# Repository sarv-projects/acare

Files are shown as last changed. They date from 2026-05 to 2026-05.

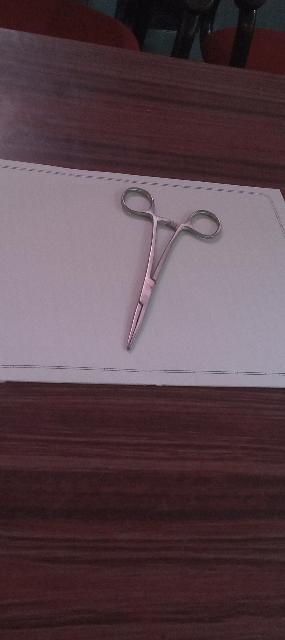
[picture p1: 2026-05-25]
6500e016-cb78-468d-8fea-698199350c50.jpg

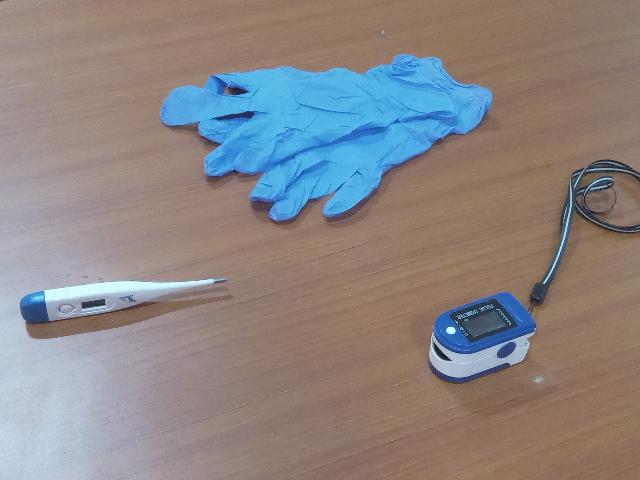
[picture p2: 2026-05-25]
c1362a88-c6d3-454c-b15d-c077ffdc3ec1.jpg

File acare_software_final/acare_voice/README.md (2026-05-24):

# ACARE: Autonomous Clinical Assistance Robot (Voice Module)

ACARE is a robotic assistant designed for clinical environments, specializing in fetching surgical tools via voice commands. This repository contains the **Voice Module**, which handles the complete audio-to-intent pipeline.

---

## 🛠️ Project Structure & File Map

All core logic is located in the `voice/` package:

| File | Purpose | Key Technology |
| :--- | :--- | :--- |
| **`main.py`** | **Entry Point** | Standalone Orchestration |
| `voice/voice_node.py` | **Master Controller** | Audio State Machine & Pipeline Logic |
| `voice/asr.py` | Real-time Transcription | Deepgram Nova-2 (Streaming) |
| `voice/tts.py` | Dual-Engine Speech | **edge-tts** (Neural) & **pyttsx3** (Safety) |
| `voice/vad.py` | Human Speech Detection | Silero VAD (v5) |
| `voice/intent_parser.py`| Command Understanding | Groq (Llama 3 8B) |
| `voice/normaliser.py` | Text Cleaning | Regex-based sanitization |
| `voice/alias_expansion.py`| Tool Mapping | Alias matching (e.g., "blade" → "scalpel") |
| `voice/keyword_monitor.py`| Emergency Monitoring | 100ms Collision Window Listener |
| `voice/assistant_agent.py`| Conversational AI | LOGGED_OUT mode (Assistant guidance) |

---

## ✨ Features Implemented (Done)

- [x] **Dual TTS Architecture**: 
  - **Normal**: Premium Azure Neural via `edge-tts` (completely free, no key needed).
  - **Emergency**: Instant `pyttsx3` offline speech for ESTOP/URGENT alerts.
- [x] **High-Speed ASR**: Real-time streaming from Deepgram with partial transcript handling.
- [x] **Safety First**: Dedicated emergency keyword thread that triggers `<200ms` ESTOP.
- [x] **Intelligent Parsing**: Validates intents with JSON schema enforcement via Groq.
- [x] **Clinical Logic**:
  - Alias expansion for surgical tools.
  - Multi-tool detection (prevents robot from grabbing two things at once).
  - Logged-out assistant mode for auth guidance.

---

## 🚀 How to Run

### 1. Setup Environment
Ensure your `.env` file contains:
* `DEEPGRAM_API_KEY`
* `GROQ_API_KEY`

Sync dependencies using `uv`:
```powershell
uv sync
```

### 2. Execute System
Launch the full standalone voice pipeline:
```powershell
python main.py
```

### 3. Interactive Commands
Once running, type these into the terminal to simulate robot states:
* `login`: Starts the surgical command session.
* `logout`: Returns to assistant guidance.
* `estop`: Forces an emergency stop.
* `resume`: Resets to standby.
* `quit`: Clean shutdown.

---

## 🎙️ Changing the Voice

We use **edge-tts** for natural speech. You can change the robot's personality in `voice/tts.py` on **Line 116**.

| Feature | Voice Name | Description |
| :--- | :--- | :--- |
| **Neutral Robotic** | `en-US-AvaNeural` | **(Current)** Clean, standard AI tone. |
| **Sophisticated** | `en-GB-SoniaNeural` | Crisp British tone, very clear. |
| **Friendly Male** | `en-US-AndrewNeural` | Calm, helpful assistant. |
| **Regional (IN)** | `en-IN-NeerjaNeural` | Natural Indian-English female tone. |

**To change:** Edit `voice/tts.py`:
```python
# Line 116
voice = "en-US-AvaNeural" 
```
You can also use `edge-tts --list-voices`  command in the terminal to list all other available voices.

---

## 🧪 Testing Sub-Modules
You can test components individually:
* **TTS Test**: `python -m voice.tts`
* **Normaliser Test**: `python -m voice.normaliser`
* **Alias Test**: `python -m voice.alias_expansion`

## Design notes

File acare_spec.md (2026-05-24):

# ACARE
## Autonomous Clinical Assistance Robot with Multimodal Biometric Authentication and Dynamic Human Handover

---

| Field | Details |
|---|---|
| Institution | Ramaiah Institute of Technology, Bengaluru |
| Department | Electronics and Communication Engineering |
| Guide | Dr. Lakshmi Shrinivasan, Associate Professor |
| Team | Sathvik Rao · Sarvesh Bhattacharyya · Shreevanth M · Shreyas S |
| Funding | ₹40,000 — Institutional Grant |
| Status | Active Development — April 2026 |

---

## DOMAIN MAP

| Domain | Scope |
|---|---|
| SOFTWARE | AI pipelines, ROS2 nodes, orchestration, admin CLI |
| HARDWARE | Mechanical, electrical, power, physical components |
| EMBEDDED / FIRMWARE | Teensy 4.1 motor control, sensor ISR loops, PID |
| INTEGRATION BOUNDARY (SOFTWARE + ELECTRONICS/EMBEDDED) | Protocol contracts between software and embedded |

---

## TABLE OF CONTENTS

- Section I — Project Overview
- Section II — Hardware Architecture
- Section III — Embedded Firmware — Teensy 4.1 / Cortex-M4 + ESP32
- Section IV — Software ↔ Embedded Integration Boundary
- Section V — ROS2 Software Architecture
- Section VI — Global Robot State Machine
- Section VII — Identity & Session Management
- Section VIII — Voice Orchestration Layer
- Section IX — Voice Command Pipeline
- Section X — Conversational Layer — LangGraph + Assistant Agent
- Section XI — Vision Pipeline — NBV Search & Detection
- Section XII — Task Planner Pipeline
- Section XIII — Emergency Stop System
- Section XIV — LiDAR Safety System
- Section XV — Response Generator — TTS
- Section XVI — Logging & Audit Trail
- Section XVII — Startup, Shutdown & Power Recovery
- Section XVIII — Admin CLI & Calibration
- Section XIX — Configuration Files
- Section XX — Directory Structure
- Section XXI — Complete Technology Stack
- Section XXII — Performance KPIs
- Section XXIII — Preliminary Work Status — March 2026
- Section XXIV — Supplementary Implementation Details
- Section XXV — Commercial Applications & Future Work
- Section XXVI — Complete System Flow & Final Decisions (Full Operational Reference)

---

## SECTION I — PROJECT OVERVIEW

### Objective

ACARE is a stationary 6-DOF semi-autonomous robotic arm designed for clinical environments — specifically plastic surgery departments — where surgical tools must be fetched and delivered to authorised staff repeatedly across long procedure shifts. The robot replaces the manual, hygiene-risk-bearing task of instrument handling by providing a voice-commanded, biometrically authenticated, autonomous pick-and-place system with human oversight.

### Core Problems Solved

- Staff fatigue from repetitive tool retrieval during 10–12-hour surgical shifts
- Hygiene risks from manual handling of sterile instruments
- Procedure delays caused by instrument unavailability or incorrect delivery
- Absence of affordable autonomous assistance solutions in Indian healthcare settings

### Scope — Finalised

- Stationary pick-and-place operation only — navigation removed from scope
- Contactless operation — entirely voice commanded, no physical input required
- Dual biometric authentication — voice and face combined for every session
- Single active user session at any time — one command per turn
- Single tool per command — multi-tool requests handled via clarification dialogue
- Next-Best-View intelligent search — not continuous scanning
- Direct handover — tool delivered from gripper directly into authenticated staff's hand

### System Architecture Summary

ACARE is a two-layer hierarchical robotic system. The high-level intelligence layer runs on a Raspberry Pi 5 using ROS2. The real-time motor control layer runs on a Teensy 4.1 (Cortex-M7).

These two layers communicate via CAN bus (preferred) or UART. All AI and software pipelines are isolated from hardware control.

- SOFTWARE — Raspberry Pi 5 + ROS2 + Python AI Nodes
- EMBEDDED / FIRMWARE — Teensy 4.1 / Cortex-M4 + ESP32 + PID + Safety ISR
- HARDWARE — 6-DOF Arm + Sensors + Power System

### Key Differentiation vs Prior Art

Unlike MOXI, TIAGo, TUG, or LIO, ACARE integrates multimodal biometric authentication (voice + face), voice-driven instrument retrieval with structured intent parsing, adaptive probabilistic vision search, and dynamic human-robot handover with real-time palm tracking — all within a layered safety architecture that separates high-level intelligence from deterministic motor control.

### Section I-B — System Assumptions & Prerequisites

**Network**

- ACARE requires stable internet connectivity during operation
- Two cloud services are mandatory: Deepgram Nova-2 (STT streaming WebSocket) and Groq API (intent parsing)
- Microsoft Edge TTS API required for natural voice responses
- If connectivity drops mid-session: voice commands stop processing; system transitions to STANDBY or ESTOP (safe deposit if holding)
- There is no offline fallback mode by design. The system either works fully or stops cleanly. Degraded mode does not exist.
- A stable Wi-Fi connection at the deployment site is a prerequisite. Mobile hotspot recommended as backup for demo.

**Power**

- Continuous 24V motor supply required
- 5V regulated logic supply required
- Power failure triggers recovery sequence on reboot

**Physical**

- Fixed workspace — robot does not navigate
- SAFE_DROP_ZONE and handover zone positions fixed at calibration
- Staff must approach from designated handover direction

### Future Work Preview

Long-term extensions include integration with hospital automation systems, smart operating room orchestration, and expansion to multi-robot clinical assistance fleets. See Section XXV for detailed commercial roadmap.

---

## SECTION II — HARDWARE ARCHITECTURE

> **HARDWARE** — All mechanical design, fabrication, PCB design, power electronics, and physical sensor mounting falls under the Hardware domain.

### Mechanical Structure

- 6-DOF serial robotic arm
- Custom 3D printed cycloidal gearboxes — 22:1 ratio at shoulder, 15:1 at elbow
- Gearbox ratios for wrist joints 4, 5, 6: [PLACEHOLDER — confirm with hardware team]
- Material: PETG high infill for gearbox bodies; aluminium sheet metal for structural load-bearing links
- Radial bearings at all rotating joints
- Precision gripper mechanism with integrated force sensor
- Bowden line pulley system for wrist actuation
- Fixed handover zone — staff approaches and receives tool directly from gripper; position encoded in config
- Fixed SAFE_DROP_ZONE — predefined emergency deposit surface on table; (x, y, z) stored in config
- Base fixation method: [PLACEHOLDER — bolted to table / clamped / weighted base — confirm]

### Joint Parameters — Required from Hardware Team

> **CRITICAL:** IK solver and planner_node cannot be built without these values.

| Joint | Name | Min Angle (rad) | Max Angle (rad) | Max Velocity (rad/s) | Home Position (rad) | Gear Ratio |
|---|---|---|---|---|---|---|
| Joint 1 | Base Rotation | [PLACEHOLDER] | [PLACEHOLDER] | [PLACEHOLDER] | 0.0 | [PLACEHOLDER] |
| Joint 2 | Shoulder | [PLACEHOLDER] | [PLACEHOLDER] | [PLACEHOLDER] | [PLACEHOLDER] | 20:1 |
| Joint 3 | Elbow | [PLACEHOLDER] | [PLACEHOLDER] | [PLACEHOLDER] | [PLACEHOLDER] | 15:1 |
| Joint 4 | Wrist Pitch | [PLACEHOLDER] | [PLACEHOLDER] | [PLACEHOLDER] | 0.0 | [PLACEHOLDER] |
| Joint 5 | Wrist Roll | [PLACEHOLDER] | [PLACEHOLDER] | [PLACEHOLDER] | 0.0 | [PLACEHOLDER] |
| Joint 6 | Gripper Rotate | [PLACEHOLDER] | [PLACEHOLDER] | [PLACEHOLDER] | 0.0 | [PLACEHOLDER] |

### Link Lengths — Required from Hardware Team

| Link | Description | Length (metres) |
|---|---|---|
| Base height | Base to shoulder joint (vertical) | [PLACEHOLDER] |
| Upper arm | Shoulder to elbow | [PLACEHOLDER] |
| Forearm | Elbow to wrist | [PLACEHOLDER] |
| Wrist | Wrist joint to gripper mount | [PLACEHOLDER] |
| Gripper | Gripper mount to fingertips | [PLACEHOLDER] |
| Total reach | Maximum horizontal reach | [PLACEHOLDER] |

### DH Parameters — Required from Hardware Team

Denavit-Hartenberg parameters needed for IK solver. Fill in after assembly.

| Joint | a (m) | alpha (rad) | d (m) | theta offset (rad) |
|---|---|---|---|---|
| 1 | [PLACEHOLDER] | [PLACEHOLDER] | [PLACEHOLDER] | [PLACEHOLDER] |
| 2 | [PLACEHOLDER] | [PLACEHOLDER] | [PLACEHOLDER] | [PLACEHOLDER] |
| 3 | [PLACEHOLDER] | [PLACEHOLDER] | [PLACEHOLDER] | [PLACEHOLDER] |
| 4 | [PLACEHOLDER] | [PLACEHOLDER] | [PLACEHOLDER] | [PLACEHOLDER] |
| 5 | [PLACEHOLDER] | [PLACEHOLDER] | [PLACEHOLDER] | [PLACEHOLDER] |
| 6 | [PLACEHOLDER] | [PLACEHOLDER] | [PLACEHOLDER] | [PLACEHOLDER] |

### Workspace Validation

Defined workspace: xmin: -0.4m to xmax: 0.4m, ymin: -0.3m to ymax: 0.3m, zmin: 0.0m to zmax: 0.5m.

Workspace reachability confirmation: [PLACEHOLDER — verify arm can physically reach all corners of defined workspace after assembly]

### Gripper Specifications

| Parameter | Value |
|---|---|
| Type | Parallel jaw |
| Finger material | [PLACEHOLDER] |
| Maximum jaw opening | [PLACEHOLDER] mm |
| Default grasp width | 25 mm (most tools) |
| Open width | 45 mm |
| Closed width | 0 mm |
| Force control mode | Yes — not simple open/close |
| Force target (normal grasp) | 3–5 N |
| Force warning threshold | 10 N |
| Force ESTOP threshold | 15 N |
| Tool retention during transport | [PLACEHOLDER — friction / mechanical lock / force hold] |
| Open time | ~500 ms |
| Close time | ~500 ms |

### Weight and Load

- Estimated arm weight: [PLACEHOLDER — total arm weight in kg]
- Maximum payload at end-effector: [PLACEHOLDER — kg, confirm motors can handle]
- Per-link weight distribution: [PLACEHOLDER]

### Actuators

- BLDC motors: 1.4 Nm Rhino Planetary Gearbox BLDC — base, shoulder, elbow joints (×3)
- Additional BLDC motors for wrist and gripper actuation
- Gripper motor controlled in force mode — not position mode
- Motor driver: [RMCS-3002l]
- Motor driver communication to Teensy: [Modbus ASCII]
- Current sensing method: [PLACEHOLDER — shunt resistor / hall sensor]

### Sensors — Full List

| Sensor | Model / Type | Location | Domain |
|---|---|---|---|
| RGBD Depth Camera | YDLIDAR HP60C | Wrist-mounted | Hardware / Software |
| Safety LiDAR | YDLIDAR T-mini-Plus | Base-mounted ~80cm | Hardware / Software |
| Joint Encoders | AS5600 Magnetic Encoder ×6 | Each joint | Hardware / Embedded |
| IMU | On MCU board | Arm base | Hardware / Embedded |
| Joint Current Sensors | Per motor phase | Motor driver board | Hardware / Embedded |
| Temperature Sensors | Per joint motor | Joint housings | Hardware / Embedded |
| Gripper Force Sensor | Analog force sensing | Gripper fingertips | Hardware / Embedded |
| Microphone | [PLACEHOLDER — model, polar pattern, USB/3.5mm] | Fixed mount near workspace | Hardware / Software |
| Speaker | [PLACEHOLDER — model, amplifier if any] | [PLACEHOLDER — mounting location] | Hardware / Software |
| I2C Multiplexer | TCA9548A | MCU board | Hardware / Embedded |

### Camera Interface

- YDLIDAR HP60C connection to Pi: [PLACEHOLDER — USB3 / proprietary — confirm interface]
- ROS2 driver package for HP60C: [PLACEHOLDER — confirm package name]
- YDLIDAR T-mini Plus connection to Pi: [PLACEHOLDER — USB / Serial — confirm]
- ROS2 driver package for T-mini Plus: [PLACEHOLDER — confirm package name]

### Microphone Specification

- Model: [PLACEHOLDER]
- Polar pattern: [PLACEHOLDER — cardioid / supercardioid recommended for OT noise rejection]
- Connection type: [PLACEHOLDER — USB / 3.5mm / XLR]
- Distance from speaker: [PLACEHOLDER — ensure sufficient separation to prevent feedback]

### Speaker Specification

- Model: [PLACEHOLDER]
- Amplifier: [PLACEHOLDER — if required]
- Mounting location: [PLACEHOLDER — near workspace, facing staff area]
- Volume requirement: sufficient to be heard in active OT environment over monitor beeps

### Cable Management

- Wrist camera cable routing: [PLACEHOLDER — flex-rated cable required through rotating joints]
- Encoder cable routing: [PLACEHOLDER — per joint, shielded recommended]
- Motor power cable gauge: [PLACEHOLDER — sized for 8A continuous per motor]
- Emergency stop button cable: direct hardwire to motor driver enable pin, no software path

### Power System

- Motor supply: 24V dedicated rail — powers all BLDC motors and motor drivers
- Logic supply: 5V regulated — powers Raspberry Pi 5, isolated from motor rail
- MCU supply: 5V or 3.3V from onboard regulator
- Common ground across all supplies — mandatory for signal integrity
- Fuse on motor supply rail — overcurrent protection
- Reverse polarity protection on all input rails
- Surge protection — motor switching transients isolated from logic supply
- EMI filtering between motor supply and Pi supply — implementation: [PLACEHOLDER — ferrite beads / LC filter / isolated transformer]
- Hardware emergency cutoff relay — physical red button wired directly to motor driver enable pin, cuts 24V immediately, independent of all software
- XT30 male connectors for battery/PSU to motor controller connections

### Connector Specifications

| Connection | Connector Type | Notes |
|---|---|---|
| Motor rail to driver | XT30 male/female | 24V, high current rated |
| Encoder to TCA9548A | [PLACEHOLDER] | I2C, shielded cable |
| Camera (HP60C) to Pi | [PLACEHOLDER] | USB3 / proprietary |
| LiDAR to Pi | [PLACEHOLDER] | USB / Serial |
| ESTOP button | Direct hardwire | To motor driver enable pin |
| Pi to MCU (CAN) | [PLACEHOLDER] | Galvanic isolation between Pi and MCU |
| CAN bus termination | [PLACEHOLDER] | 120 ohm termination resistors at both ends |

### Thermal Management

- Raspberry Pi 5 cooling: active fan required — confirmed risk of thermal throttling under full load
- Pi 5 thermal test: must run under full load (YOLOv11 + SpeechBrain + ROS2 + TTS) for 30 minutes before demo — confirm no throttling
- Motor housing ventilation: [PLACEHOLDER — confirm passive or active cooling per motor]
- Enclosure thermal design: [PLACEHOLDER — if enclosed, ensure airflow]

### Physical Layout Constraints

- SAFE_DROP_ZONE: flat horizontal surface within arm reach, defined during calibration, stored in config as (x, y, z)
- Handover zone: fixed position, staff approaches from designated direction and receives directly from gripper
- LiDAR mounted at approximately 80cm height — scans horizontal plane at torso level
- Camera wrist-mount angle: calibrated during setup, extrinsics stored in config
- Arm base mounting: [PLACEHOLDER — how base is fixed to table/surface]

---

## SECTION III — EMBEDDED FIRMWARE — Teensy 4.1 / Cortex-M4 + ESP32

> **EMBEDDED / FIRMWARE** — All firmware, PID implementation, ISR routines, watchdog logic, and calibration sequences fall under the Embedded domain.

### MCU Selection

Teensy 4.1 selected for current implementation — Cortex-M7 at 600MHz. Final target is a custom PCB integrating Cortex-M4 for motor control and ESP32 for Pi communication only. ESP32 not used for motor control — WiFi jitter is incompatible with deterministic PID.

### PCB Design Specification

- Custom PCB status: [PLACEHOLDER — in progress]
- MCU: Cortex-M4 for motor control
- WiFi/BT: ESP32 for Pi communication only
- Layer count: [PLACEHOLDER]
- Connector types: [PLACEHOLDER]
- Galvanic isolation: [PLACEHOLDER — how implemented between Pi and MCU]
- Schematic reference: [PLACEHOLDER — attach or link schematic]

### Control Loop Architecture

| Loop | Frequency | Responsibility |
|---|---|---|
| Velocity PID | 200 Hz | Motor velocity regulation from position derivative |
| Position PID | 200 Hz | Joint angle tracking from encoder feedback |
| Sensor Read | 100 Hz | Encoder, current, temperature, gripper force, IMU |
| Status Publish to Pi | 50 Hz | JSON status packet over CAN/UART |
| Heartbeat Check | 5 Hz | Verify Pi heartbeat received within 500ms window |

### Per-Joint Control Stack

```
Position PID → Velocity PID → Frequency → Motor driver → BLDC motor
     ↑ Encoder feedback + Current feedback
```

### PID Parameters — Initial Values

> Note: these are starting values for tuning. Final values determined empirically after assembly.

| Joint | Position Kp | Position Ki | Position Kd | Velocity Kp | Velocity Ki | Velocity Kd |
|---|---|---|---|---|---|---|
| Joint 1 (Base) | [PLACEHOLDER] | [PLACEHOLDER] | [PLACEHOLDER] | [PLACEHOLDER] | [PLACEHOLDER] | [PLACEHOLDER] |
| Joint 2 (Shoulder) | [PLACEHOLDER] | [PLACEHOLDER] | [PLACEHOLDER] | [PLACEHOLDER] | [PLACEHOLDER] | [PLACEHOLDER] |
| Joint 3 (Elbow) | [PLACEHOLDER] | [PLACEHOLDER] | [PLACEHOLDER] | [PLACEHOLDER] | [PLACEHOLDER] | [PLACEHOLDER] |
| Joint 4 (Wrist Pitch) | [PLACEHOLDER] | [PLACEHOLDER] | [PLACEHOLDER] | [PLACEHOLDER] | [PLACEHOLDER] | [PLACEHOLDER] |
| Joint 5 (Wrist Roll) | [PLACEHOLDER] | [PLACEHOLDER] | [PLACEHOLDER] | [PLACEHOLDER] | [PLACEHOLDER] | [PLACEHOLDER] |
| Joint 6 (Gripper) | [PLACEHOLDER] | [PLACEHOLDER] | [PLACEHOLDER] | [PLACEHOLDER] | [PLACEHOLDER] | [PLACEHOLDER] |

- Anti-windup strategy: [PLACEHOLDER — clamping / back-calculation]
- Feed-forward terms: [PLACEHOLDER — gravity compensation per joint]
- PWM carrier frequency: [PLACEHOLDER — kHz]
- PWM resolution: [PLACEHOLDER — bits]
- FOC switching frequency: [PLACEHOLDER — kHz]
- Dead time for complementary outputs: [PLACEHOLDER — ns]

### Encoder Reading Implementation

- I2C clock speed for AS5600: [PLACEHOLDER — Hz, typically 400kHz]
- Address assignment per TCA9548A channel: [PLACEHOLDER — channel 0 = joint 1, etc.]
- Read method: [PLACEHOLDER — interrupt-driven / polling at 100Hz]
- Encoder count to angle conversion: `angle_rad = (raw_count / 4096) × 2π`
- Zero position calibration storage: [PLACEHOLDER — EEPROM / Flash — location and format]
- Exponential moving average filter on encoder: `filtered = 0.7 × raw + 0.3 × prev`

### Embedded Internal State Machine

| State | Description | Allowed Transitions |
|---|---|---|
| IDLE | Powered, no commands, holding position | → POSITION_CONTROL, → CALIBRATION |
| POSITION_CONTROL | Executing joint position targets from Pi | → GRIPPER_CONTROL, → ESTOP, → FAULT, → IDLE |
| GRIPPER_CONTROL | Force-mode gripper operation | → POSITION_CONTROL, → ESTOP, → FAULT |
| ESTOP | PWM disabled, motors free or braked | → IDLE (only after CLEAR_FAULT from Pi) |
| FAULT | Unrecoverable hardware fault detected | → ESTOP, requires admin reset |
| CALIBRATION | Joint homing sequence | → IDLE on completion |

### Firmware Safety Protections — Non-Negotiable

- Current clamp: if joint_current > 8A for >100ms → ESTOP
- Thermal shutdown: if joint_temp > 65°C → reduce velocity 50%. If temp > 75°C → ESTOP
- Encoder soft limits: if encoder value exceeds mechanical boundary → ESTOP
- Watchdog timer: firmware hang → MCU hardware reset
- Pi heartbeat watchdog: no heartbeat for 500ms → disable all PWM → ESTOP
- Hardware ESTOP pin: physical red button → cuts PWM immediately at hardware level
- Boot calibration timeout: if joint does not reach limit switch within [PLACEHOLDER] seconds → FAULT

### Fault Code Definitions

| fault_code | Meaning | Recovery |
|---|---|---|
| 0 | OK — no fault | — |
| 1 | Overcurrent — joint current > 8A | CLEAR_FAULT after inspection |
| 2 | Overtemperature — joint temp > 75°C | CLEAR_FAULT after cooling |
| 3 | Encoder soft limit exceeded | CLEAR_FAULT after repositioning |
| 4 | Velocity limit exceeded > 120 deg/s | CLEAR_FAULT |
| 5 | Gripper force spike > 15N | CLEAR_FAULT after inspection |
| 6 | Heartbeat timeout — Pi silent > 500ms | Auto-recovers when heartbeat resumes |
| 7 | Firmware watchdog reset | CLEAR_FAULT after admin review |
| 8 | Boot calibration timeout | Admin must manually home joint |

### Pre-Threshold Warning Margins

- Joint current: Warning at 6A (−25% velocity). Hard ESTOP at 8A.
- Joint temperature: Warning at 55°C (−25% velocity). Slowdown at 65°C (−50%). ESTOP at 75°C.
- Gripper force: Target 3–5N. Warning at >10N. ESTOP at >15N.
- Joint velocity: Operational limit 80 deg/s. Hard ESTOP at 120 deg/s.

### Gripper Force Control Logic

- Force control mode — not simple open/close
- Apply increasing current until target force threshold reached, then maintain minimum holding torque
- Force spike > 15N → immediate ESTOP (unexpected contact)
- Object drop detection: force drops to zero during HOLDING → notify planner_node via /motion_feedback
- Gripper fully opens before arm approaches grasp position — GRIPPER_OPEN awaited first

### Boot Calibration Sequence

- Move each joint slowly toward mechanical limit switch, detect contact, zero encoder offset
- Repeat for all 6 joints in defined sequence (joint 1 → 6)
- Set all joint soft-limits from calibrated zeros
- Report CALIBRATION_COMPLETE to Pi
- Timeout per joint: [PLACEHOLDER] seconds — if not reached → fault_code 8

---

## SECTION IV — SOFTWARE ↔ EMBEDDED INTEGRATION BOUNDARY

> **INTEGRATION BOUNDARY** — Protocol contract between embedded_interface_node (software) and Teensy 4.1 firmware. Both teams must implement their side identically.

### Physical Communication Layer

- Primary: UART — recommended for noise immunity and multi-drop support
- Fallback: UART at minimum 1 Mbps
- UART frame format: [PLACEHOLDER — standard 11-bit / extended 29-bit]
- Byte packing: little-endian, float32 IEEE 754
- Do not use I2C or SPI for Pi ↔ MCU communication
- Galvanic isolation: [PLACEHOLDER — implementation between Pi and MCU]
- UART format — framing: [PLACEHOLDER — start byte, length, payload, CRC]

### Startup Handshake

- On boot, MCU waits for first HEARTBEAT from Pi before entering IDLE
- Pi embedded_interface_node waits for CALIBRATION_COMPLETE from MCU before accepting any commands
- If Pi boots before MCU calibration completes: Pi polls, retries every 500ms, max 60 seconds
- If MCU does not send CALIBRATION_COMPLETE within 60 seconds: Pi publishes ESTOP, TTS: 'Calibration failed. Admin required.'

### Pi Heartbeat — Implementation

```cpp
// embedded_interface_node (C++) sends every 200ms:
{ "command":"HEARTBEAT", "timestamp": unix_ms, "robot_state": current_state_string }

// MCU side:
if(millis() - last_heartbeat_ms > 500){ disable_all_pwm(); enter_estop(); }
```

### Pi → MCU Commands

| Command | Fields | Description |
|---|---|---|
| MOVE | joint_angles[6] (float32), velocity_scale (float32), accel_limit (float32) | Move all joints to target positions |
| GRASP | force_target (float32, Newtons) | Close gripper in force control mode |
| RELEASE | — | Open gripper fully |
| MOVE_NEUTRAL | — | Return to predefined neutral position |
| ESTOP | — | Immediate PWM disable |
| CLEAR_FAULT | — | Reset after fault resolution |
| CALIBRATE | — | Trigger boot calibration sequence |
| HEARTBEAT | timestamp (int64), robot_state (string) | 200ms keepalive |

### MCU → Pi Status (50 Hz)

| Field | Type | Description |
|---|---|---|
| joint_positions | float32[6] | Current joint angles in radians |
| joint_velocities | float32[6] | Current joint velocities in rad/s |
| joint_currents | float32[6] | Per-joint motor current in Amperes |
| temperatures | float32[6] | Per-joint temperature in °C |
| gripper_force | float32 | Current gripper contact force in N |
| imu | roll, pitch, yaw (float32) | Arm orientation from IMU |
| fault_code | int32 | 0 = OK, see fault code table for non-zero values |
| control_state | string | IDLE / POSITION_CONTROL / GRIPPER_CONTROL / ESTOP / FAULT |

### Workspace Boundary Contract

Software enforces workspace limits before sending any MOVE command. Embedded enforces joint soft-limits independently. Both layers protect — neither relies solely on the other.

```
workspace: xmin:-0.4  xmax: 0.4  ymin:-0.3  ymax: 0.3  zmin: 0.0  zmax: 0.5  (metres)
```

---

## SECTION V — ROS2 SOFTWARE ARCHITECTURE

> **SOFTWARE** — All ROS2 nodes, topics, message definitions, launch files, and Python AI logic fall under the Software domain.

### Execution Model

- MultiThreadedExecutor runs all nodes concurrently. No monolithic Python process.
- One node per concern. Nodes communicate exclusively via typed ROS2 topics.
- Vision inference (YOLOv11) and speaker verification (SpeechBrain) must not run simultaneously.
- embedded_interface_node runs in a dedicated MutuallyExclusive callback group — heartbeat cannot share thread pool with vision or TTS.

### Node Inventory

| Node | Package | Language | Responsibility |
|---|---|---|---|
| voice_node | acare_voice | Python | Audio I/O, VAD, STT, TTS, emergency keyword thread, assistant agent (LOGGED_OUT) |
| dialogue_node | acare_dialogue | Python | LangGraph, intent clarity, context resolution, interruption, assistant agent routing |
| auth_node | acare_auth | Python | Dual biometric verification, session management, enrolment, scripted auth flow, handover face check |
| vision_node | acare_vision | Python | YOLOv11 ONNX, NBV search, Bayesian probability map, fake detection, 3D localisation, hand tracking |
| planner_node | acare_planner | Python | Full task orchestration, IK, handover protocol (3-check), state transitions, latency tracking, world state snapshot |
| embedded_interface_node | acare_embedded_interface | C++ | CAN/UART bridge, heartbeat, command serialisation — MutuallyExclusive callback group |
| safety_node | acare_safety | Python | LiDAR proximity, sensor threshold monitoring, graded severity (WARNING/CRITICAL/ESTOP) |
| state_manager | acare_planner | Python | Global robot state machine, atomic transition enforcement, graded severity handling |
| log_node | acare_logging | Python | SQLite audit trail, full pipeline latency fields, log rotation |
| admin_node | acare_admin | Python | CLI interface, enrolment, calibration, demo mode, diagnostics |

### Node Crash Recovery

- Lightweight `supervisor.py` (separate from ROS2) monitors node health and auto-restarts non-critical nodes
- Auto-restart (non-critical): log_node, admin_node, dialogue_node
- No auto-restart (critical): safety_node, embedded_interface_node, state_manager, planner_node
- On critical node crash: publish ESTOP, TTS: 'System fault detected. Admin required.', State → ERROR

### ROS2 QoS Policy

| Topic Category | QoS | Rationale |
|---|---|---|
| Sensor data (/motion_feedback, /lidar_scan) | BEST_EFFORT | Drop stale data; always use latest |
| Commands (/arm_command, /gripper_command, /emergency_stop) | RELIABLE | Guaranteed delivery — never drop |
| State topics (/robot_state, /state_transition, /safety_alert) | RELIABLE | All nodes must see state changes |
| Logging (/log_event) | BEST_EFFORT | Log loss acceptable; never block pipeline |

### Topic Structure

| Topic | Message Type | Publisher → Subscriber |
|---|---|---|
| /robot_state | RobotState | state_manager → all nodes |
| /state_transition | StateTransition | any node → state_manager |
| /raw_transcript | Transcript | voice_node → dialogue_node |
| /intent_result | Intent | dialogue_node → auth_node |
| /validated_intent | ValidatedIntent | auth_node → planner_node |
| /emergency_stop | EmergencySignal | voice_node / safety_node → all nodes + embedded_interface |
| /auth_request | AuthRequest | dialogue_node → auth_node |
| /auth_result | AuthResult | auth_node → planner_node |
| /vision_search_request | VisionSearchRequest | planner_node → vision_node |
| /vision_result | VisionResult | vision_node → planner_node |
| /probability_update | ProbabilityUpdate | vision_node → vision_node (internal) |
| /arm_command | ArmCommand | planner_node → embedded_interface_node |
| /gripper_command | GripperCommand | planner_node → embedded_interface_node |
| /motion_feedback | MotionFeedback | embedded_interface_node → planner_node |
| /lidar_scan | LaserScan | safety_node (internal), velocity scale → planner |
| /safety_alert | SafetyAlert | safety_node → planner_node + state_manager |
| /log_event | LogEvent | all nodes → log_node |
| /vision_status | VisionStatus | vision_node → planner_node (LOADING / READY) |
| /hand_status | HandStatus | vision_node → planner_node (handover hand detection) |
| /tts_request | String | dialogue_node, planner_node → voice_node |

### Custom Message Definitions — acare_msgs Package

```
RobotState.msg
string state  # OFFLINE|LOGGED_OUT|STANDBY|LISTENING|PROCESSING|EXECUTING|HOLDING|HANDOVER|ESTOP|ERROR
string active_user_id

Intent.msg
string tool
string action
string destination  # always 'user_handover' — hardcoded in planner
float32 confidence

ValidatedIntent.msg
string tool
string action
string user_id
bool authenticated

SafetyAlert.msg
string reason
string source  # voice|lidar|current|temp|velocity|gripper|network
string severity  # WARNING|CRITICAL|ESTOP

HandStatus.msg
bool hand_detected
bool is_open
bool palm_up
float32 x
float32 y
float32 z
float32 confidence

AuthResult.msg
string user_id
string name
string role
bool success
bool face_verified
float32 face_confidence

VisionResult.msg
bool found
string tool
float32 x
float32 y
float32 z
float32 confidence
string zone
string[] candidates  # alternative detection candidates for IK fallback

ArmCommand.msg
string command  # MOVE|GRASP|RELEASE|MOVE_NEUTRAL|ESTOP|CLEAR_FAULT|CALIBRATE|HEARTBEAT
float32[] joint_angles
float32 velocity_scale  # 0.0–1.0, set by safety_node proximity zone
bool blocking

MotionFeedback.msg
bool success
string phase  # PRE_GRASP|GRASP|HOLDING|HANDOVER|NEUTRAL|VIEWPOINT
string error  # empty if success

LogEvent.msg
string event_type
string user_id
string tool
string state
string description
int64 timestamp
int64 voice_e2e_ms    # VAD trigger → validated_intent published
int64 vision_search_ms  # search start → VisionResult received
int64 motion_ms       # MOVE command → MotionFeedback.success
int64 total_task_ms   # ValidatedIntent → handover complete
string safety_severity  # WARNING|CRITICAL|ESTOP for safety events

EmergencySignal.msg
string reason
string source
```

### Launch File

```python
# ros2 launch acare_bringup acare.launch.py
def generate_launch_description():
    return LaunchDescription([
        Node(package="acare_voice",              executable="voice_node"),
        Node(package="acare_dialogue",           executable="dialogue_node"),
        Node(package="acare_auth",               executable="auth_node"),
        Node(package="acare_vision",             executable="vision_node"),
        Node(package="acare_planner",            executable="planner_node"),
        Node(package="acare_planner",            executable="state_manager"),
        Node(package="acare_safety",             executable="safety_node"),
        Node(package="acare_embedded_interface", executable="interface_node"),
        Node(package="acare_logging",            executable="log_node"),
        Node(package="acare_admin",              executable="admin_node"),
    ])
```

---

## SECTION VI — GLOBAL ROBOT STATE MACHINE

> **SOFTWARE** — Enforced by state_manager node. Embedded firmware has its own independent state machine.

| State | Description | Allowed Transitions |
|---|---|---|
| OFFLINE | System idle, no processes running | → LOGGED_OUT on boot |
| LOGGED_OUT | System running, no active session | → STANDBY on login |
| STANDBY | Session active, awaiting command | → LISTENING on voice, → LOGGED_OUT on logout |
| LISTENING | VAD active, STT processing | → PROCESSING on valid command, → STANDBY on timeout |
| PROCESSING | Intent resolved, vision searching | → EXECUTING on tool found + IK solved, → STANDBY if not found |
| EXECUTING | Arm in motion, approaching grasp | → HOLDING on grasp confirmed, → ESTOP on trigger |
| HOLDING | Object grasped, moving to handover | → HANDOVER on arrival, → ESTOP on trigger |
| HANDOVER | At handover zone, 3-check verification in progress | → STANDBY on collection confirmed, → STANDBY on timeout |
| ESTOP | All motion halted, safe deposit if holding | → STANDBY on authorised resume |
| ERROR | Unrecoverable fault | → OFFLINE on admin reset |
| SAFE_DEPOSIT | Planner-internal transient — controlled move to drop zone. Not externally published. | → ESTOP on deposit confirmed |

### Logout Rules

- Logout command accepted only from STANDBY or ESTOP states
- If state is EXECUTING, HOLDING, or HANDOVER — reject logout with TTS response
- Staff may say 'stop' first → ESTOP with safe deposit → logout proceeds
- Session inactivity timeout: 5 minutes of no command in STANDBY → auto-logout with TTS notification

### Graded Safety Severity — State Manager Integration

| Severity | Trigger Example | State Manager Response |
|---|---|---|
| WARNING | joint_current > 6A, temp > 55°C, person 400–600mm | Notify planner to reduce velocity. Log WARNING. TTS: 'Caution — operating at reduced speed.' |
| CRITICAL | temp > 65°C, velocity near limit | Planner reduces velocity 50%. Continue task. Log CRITICAL. TTS: 'Warning — thermal limit approaching.' |
| ESTOP | current > 8A, lidar < 400mm, voice keyword | Immediate ESTOP — safe deposit if holding. All motion halted. State → ESTOP. |
## SECTION VII — IDENTITY & SESSION MANAGEMENT

> **SOFTWARE** — Registration, login, session lifecycle, runtime checks, and handover verification are Software responsibilities. Biometric models run on Pi. Runtime voice consistency verification ensures commands originate from the authenticated user throughout the session, enabling secure contactless interaction in sterile environments.

> **FINAL DECISION:** Authentication is voice biometric (SpeechBrain d-vector) + face embedding (MobileNet) only. No username, no password, no typing anywhere in the system. Registration requires admin CLI only. No self-registration. Face + voice both enrolled at registration time. Face enrolment requires camera operational.

### Two-Layer Identity Model

Layer 1 is full dual-biometric authentication at login. Layer 2 is a lightweight voice consistency check per command during the session.

### Layer 1 — Registration (Admin Only, One-Time)

```
Admin runs: python admin.py enrol --name "Dr. Sharma" --role surgeon

Step 1 — Voice enrolment:
  Robot says: "Please say the passphrase three times."
  User speaks passphrase × 3.
  SpeechBrain extracts d-vector per utterance.
  Average of 3 d-vectors = voice_embedding (stored).

Step 2 — Face enrolment (camera must be operational):
  Robot says: "Please look at the camera."
  Camera captures 10 frames.
  MobileNet extracts face embedding per frame.
  Average of 10 embeddings = face_embedding (stored).

Step 3 — Storage:
  unique_id = hash(voice_embedding + face_embedding + timestamp)
  Stored in users.db (encrypted):
    { unique_id, name, role, voice_embedding, face_embedding, registered_at, active }

Step 4 — Confirmation:
  TTS: "{name} registered successfully."
```

### Layer 1 — Login Flow

```
State: LOGGED_OUT, robot on standby, arm pointing downward.

Step 1 — Passive face detection (always-on, MediaPipe FaceDetection):
  Robot continuously scans for faces in front arc.
  No TTS, no prompt. Silent background scan.

Step 2 — Face detected:
  MobileNet compares face embedding vs all enrolled users.
  Best match found above threshold (0.78) → candidate_user identified.
  Robot says: "Welcome, {name}. Say confirm to log in."

Step 3 — Voice biometric simultaneously:
  As user says "confirm", Deepgram transcribes.
  SpeechBrain extracts d-vector from that utterance.
  Cosine similarity vs stored voice_embedding of candidate_user.
  Threshold: 0.85.

Step 4 — Both checks pass:
  Session created. active_user_id set in state_manager.
  TTS: "Logged in as {name}. How can I assist?"
  State → STANDBY.

Step 5 — Face check passes, voice fails:
  TTS: "Having trouble recognising your voice. Please try again."
  Retry once. Still fails → TTS: "Identity not confirmed. Please contact admin."
  No session created.

Step 6 — No face match found after 10s passive scan:
  No TTS. Continue passive scan. Robot stays on standby.

Step 7 — Manual fallback (user speaks first):
  assistant_agent (llama-3.1-8b-instant) handles conversation.
  Guides user through auth flow via dialogue.
  TTS: "I am ACARE. Please look at the camera to log in."
```

### Auth Flow — Scripted State Machine (Not Free Conversation)

The auth flow is a scripted state machine coordinated between dialogue_node and auth_node. It is not free conversational AI. Each step is a defined state with a fixed prompt and expected response type.

| Step | System Action | User Expected Response |
|---|---|---|
| 1. Detection | Passive face scan detects face | No response needed |
| 2. Greeting | TTS: 'Welcome {name}. Say confirm to log in.' | 'Confirm' — voice biometric sampled simultaneously |
| 3. Verification | d-vector extracted from confirmation utterance | — |
| 4. Session created | TTS: 'Logged in as {name}. How can I assist?' | Voice command or ACARE query |
| 5. Manual fallback | TTS: 'Please identify yourself.' | Staff says name or passphrase |
| 6. Failure | TTS: 'Identity not recognised. Please contact admin.' | Admin required |

### Layer 2 — Runtime Voice Consistency Check

```
Every command after login:
  Deepgram transcribes utterance.
  SpeechBrain extracts d-vector from that utterance.
  Cosine similarity vs LOGGED-IN user's voice_embedding only (not all enrolled users).
  Threshold: 0.85.

3 consecutive failures:
  TTS: "Having trouble recognising your voice. Please re-confirm identity."
  Lightweight re-verification: say passphrase again.
  Pass → continue, flag in log for re-enrolment suggestion.
  Fail → log VOICE_DRIFT_DETECTED. Session continues (not terminated — too aggressive for OT).
  Hard session kill on voice drift is NOT implemented.
```

- Per command: short d-vector extracted from current utterance
- Cosine similarity against LOGGED-IN user only (not all enrolled users)
- 3 consecutive low-similarity turns: TTS: 'Having trouble recognising your voice. Please re-confirm identity.'
- Lightweight re-verification: Pass → continue, flag for re-enrolment suggestion. Fail → TTS: 'Please re-enrol at your next convenient time. Session continues for now.'
- Log: VOICE_DRIFT_DETECTED — hard session termination on drift is too aggressive for clinical use

### Session Lifecycle

```
Login → session created, active_user_id set, inactivity_timer = 5 minutes.

Every command received → inactivity_timer resets.

Inactivity timer expires (5 min, no command in STANDBY):
  TTS: "Session timeout. Logging out {name}."
  Session terminated. active_user_id cleared.
  State → LOGGED_OUT.
  Deepgram WebSocket closed.
  Passive face detection resumes.

Optional hard TTL: 2 hours of total session time regardless of activity.
  Configurable in system.yaml: session_hard_ttl_seconds (default: 7200).
  On expiry: same as inactivity timeout.
  Recommended for long surgical shifts.
```

### Logout Rules

```
"Logout" accepted only from: STANDBY or ESTOP states.

If state is EXECUTING, HOLDING, or HANDOVER:
  TTS: "Cannot log out during active task."
  Command rejected. Task continues.

If staff needs to leave mid-task:
  Say "stop" → ESTOP → safe deposit → then "logout" accepted.

On logout:
  TTS: "Goodbye, {name}."
  Session terminated.
  Deepgram WebSocket closed.
  probability_map serialised to yaml.
  State → LOGGED_OUT.
  Passive face detection resumes.
```

### Handover — Multi-Modal Verification (Three-Check)

Dynamic Human–Robot Handover: The system performs an incremental approach toward the user's palm while continuously updating the target position based on real-time depth-based palm tracking.

Before releasing tool at handover zone, planner enforces three sequential checks:

**Check 1 — Continuous Face Verification**

- auth_node monitors camera every 0.5s during HANDOVER state
- Cosine similarity against logged-in user embedding, threshold 0.78–0.80
- 3 consecutive failures → hold tool, TTS: 'Please face the camera.'

```
Attempt 1: Default Z. Wait 8s for face.
  Found → proceed to HAND_DETECT.
  Not found → agentic: HANDOVER_Z_UP (+5cm). Move arm up.
Attempt 2: Z+5cm. Wait 8s for face.
  Found → proceed.
  Not found → agentic: HANDOVER_Z_DOWN (-5cm from default). Move arm down.
Attempt 3: Z-5cm. Wait 8s for face.
  Found → proceed.
  Not found → agentic: HANDOVER_VOICE_HAND_ONLY.
    TTS: "Face verification unavailable. Proceeding with voice and hand confirmation only."
    Log: FACE_VERIFY_SKIPPED (admin review required).
    face_verified = False. face_skipped = True.
    Proceed to HAND_DETECT regardless.
```

> Note: Wrist camera is fixed to arm and cannot pan independently. User may be leaning over patient, not facing robot. The Z-height search approach solves this without additional hardware.

**Check 2 — Hand Detection**

- vision_node runs MediaPipe Hands during HANDOVER state
- Publishes /hand_status: {detected, is_open, palm_up, x, y, z, confidence}
- Open palm facing upward in handover zone required before voice prompt
- If hand not detected: TTS: 'Please place your open palm under the gripper.'
- If hand detected but not open: TTS: 'Please open your palm.'
- Dynamic handover: arm makes incremental approach toward palm center using /hand_status (x,y,z) to update target position in real-time. Each position update validated by SafetyKernel.validate_move(). Velocity during palm approach: 0.3 (very slow, contact-safe).
- User says "lower" or "higher" during HAND_DETECT: arm adjusts ±5cm in Z. New pose validated by SafetyKernel. Preference stored in UserProfile.handover_z_offset for next session.

```
Wait for: hand_detected=True AND is_open=True AND palm_up=True.
Timeout: 10s first attempt, 8s second attempt.
If not detected after 2 attempts:
  TTS: "Please open your palm and hold it steady."
  Wait 8s more.
  Still not detected → handover timeout path.
```

**Check 3 — Voice Confirmation**

- TTS: 'Say take to receive.'
- Staff says 'take' or 'yes'
- Runtime voice consistency check against logged-in user passes
- Both must pass (keyword detected AND voice matches)
- Timeout: 5s
- If voice matches but keyword not detected: TTS: "Say 'take' to receive." Retry once.
- If voice does not match: TTS: "Voice not recognised." Hold tool. Retry once.
- After 2 failures: handover timeout path.
- All three checks passed → RELEASE gripper

### SafetyKernel Release Gate

```python
SafetyKernel.validate_release(world, face_verified, hand_detected, voice_confirmed)
# Hand detected AND voice confirmed are BOTH required.
# Face is advisory — if face_verified is False but the other two pass:
#   returns (True, "FACE_SKIPPED — logged")
# If hand or voice fails → returns (False, reason)
```

### Handover Substates (planner-internal)

```
APPROACHING → FACE_VERIFY → HAND_DETECT → VOICE_CONFIRM → RELEASING → COMPLETE
```

### Handover Timeout

- 30 seconds total for all three checks combined
- Timeout expires → TTS: 'No collection detected. Returning {tool} to tray.'
- ArmCommand: MOVE to SAFE_DROP_ZONE → RELEASE → Log: HANDOVER_TIMEOUT → State → STANDBY

### Height Adjustment Per User

- Staff can say 'lower' or 'higher' during handover to adjust arm position
- Adjustment: ±5cm in Z per command
- Clamps to [-0.15, +0.15] (±15cm range)
- Preference stored per user in users.db — applied automatically on next handover

### Multi-User & Unauthorised Voice Handling

- One active session at any time. Second staff approach → TTS: '{staff_A} is currently logged in.'
- Two-staff simultaneous speech: command rejected. TTS: 'Command not processed. Only {name} can issue commands.' Log: UNAUTHORISED_VOICE_ATTEMPT

---

## SECTION VIII — VOICE ORCHESTRATION LAYER

> **SOFTWARE** — voice_node owns all audio hardware access, VAD, STT, TTS, microphone mute logic, and emergency keyword thread.

### TTS Engine — Dual Approach (Finalised)

- ESTOP / critical safety messages: pyttsx3 — zero latency, fully offline, instant, zero dependency
- All other responses (normal commands, assistant agent): Microsoft Edge TTS (switched from initially planned Google Cloud TTS)
- Offline fallback (if no internet): Kokoro ONNX INT8 — local, natural voice, Pi-compatible, Apache 2.0
- 'ACARE' must be replaced with 'A-Care' before all speak() calls to prevent mispronunciation
- On Windows development: reinitialise pyttsx3 engine per speak() call to avoid known Windows single-call bug
- Priority queue: ESTOP and urgent messages jump to front, current audio hard-cut
- Rate: 150 words per minute (slightly deliberate for OT clarity)
- Microphone hard-muted during TTS playback. 300ms buffer after TTS to prevent echo triggering VAD.

### Audio State Machine — Internal to voice_node

| State | Description | Allowed Transitions |
|---|---|---|
| IDLE | Mic off, TTS off | → LISTENING when robot enters STANDBY |
| LISTENING | VAD active, mic open, Deepgram WebSocket open | → TRANSCRIBING on utterance complete |
| TRANSCRIBING | Deepgram processing, mic still open | → SPEAKING when response ready, → LISTENING if no response |
| SPEAKING | TTS playing, mic hard-muted | → LISTENING after TTS complete + 300ms buffer |
| ESTOP_LISTEN | Emergency keyword thread only — always active, never muted | Parallel to all states |

### Assistant Agent — LOGGED_OUT State

- Activates automatically when state = LOGGED_OUT and voice input detected
- Uses Groq llama-3.1-8b-instant, temperature 0.3, max 150 tokens
- Bounded to two contexts only: ACARE self-introduction and guided auth flow
- Professional, clinical tone — 1–3 sentences maximum, no small talk
- Conversation history maintained per session. reset_conversation() called on new session start.
- History capped at last 20 turns — older turns summarized to prevent Pi RAM exhaustion
- If user asks to fetch a tool: TTS: 'Authentication required before I can fetch tools.'

```
Standby behaviours when LOGGED_OUT:
  Handles casual conversation.
  Introduces itself: "I am A-Care. I can assist surgical staff with instrument retrieval.
  You need to be registered to use my features. Are you registered?"
  If user asks to fetch a tool: "Authentication required before I can fetch tools."
  If user asks to register: guides them to call admin.
  If user asks to login: begins login flow (face + voice).
  Bounded to: self-introduction, auth guidance. No small talk beyond 1-3 sentences.
```

### Deepgram WebSocket — Streaming Implementation

- Audio streamed chunk-by-chunk every 32ms — not sent as completed utterance after VAD fires
- send_chunk() called every 32ms from VAD callback — streams raw PCM int16 bytes
- float32 audio × 32767 → int16 bytes → sent via run_coroutine_threadsafe into background async loop
- Background thread hosts its own asyncio event loop — separate from main thread
- Session login → open WebSocket (kept alive for session duration)
- Session logout → close WebSocket cleanly
- Unexpected drop → 3 retries with exponential backoff (500ms, 1s, 2s) → TTS: 'Voice service unavailable.'

### Deepgram Partial vs Final Transcript Handling

```python
on_message(result):
    if not result.is_final:
        keyword_monitor.check_partial(sentence)  # ESTOP detection only
        return
    if result.is_final and result.speech_final:
        if keyword_monitor.estop_active:
            return  # drop silently — ESTOP is active
        pass_to_normaliser(result.transcript)
```

### ESTOP Keyword Monitor — Implementation Details

- Separate always-on thread monitoring Deepgram partial transcripts. Never muted.
- Keywords: stop, halt, emergency, abort, ruko, bas
- Acts on partial transcript — target latency < 200ms from word to ESTOP published
- 100ms collision window via threading.Timer: 'stop, actually bring the scalpel' → timer cancelled
- Word-boundary matching only: text.split() with punctuation stripped — 'stroke', 'stopped' do not trigger
- estop_active flag: once ESTOP confirmed, all transcripts dropped until resume() called
- resume() only callable by authenticated staff in ESTOP state

```
ESTOP Keyword + Normal Command Collision — Decision Tree:

ESTOP keyword detected in partial transcript ↓
  100ms hold window — check if more speech follows
  More speech detected → not ESTOP → pass full utterance to STT pipeline normally
  No more speech → confirm ESTOP, trigger immediately
```

### Mic Mute During TTS

```python
async def speak(text, priority=NORMAL):
    if priority == URGENT:
        tts_queue.clear()
        tts.stop_current()
        mute_microphone()
    await tts.play(text)
    await asyncio.sleep(0.3)  # prevents TTS tail from triggering VAD
    unmute_microphone()
    audio_state → LISTENING
```

---

## SECTION IX — VOICE COMMAND PIPELINE

> **SOFTWARE** — No offline STT or intent fallback. System either works fully or stops cleanly.

### Network Failure Policy — Final

- No fuzzy keyword fallback, no Vosk offline STT, no Whisper fallback
- Deepgram failure → TTS: 'Voice service unavailable.' → STANDBY (or safe deposit if holding)
- Groq failure → TTS: 'Service temporarily unavailable.' → STANDBY (or safe deposit if holding)
- Edge TTS failure → fallback to Kokoro ONNX automatically (local)
- Holding object past 5-second threshold when network fails → safe deposit → ESTOP

### Complete Pipeline Flow

```
Microphone (32ms chunks, 16kHz, float32) ↓ streaming continuously

Silero VAD (every chunk, 512 samples minimum)
  pause < 1.5s → thinking, pipeline waits
  pause > 3s + min 1s speech → utterance complete
  < 1s total speech → ignore (noise/cough) ↓

all chunks also streamed in parallel:
Emergency Keyword Thread (always-on, Deepgram partial transcripts)
  Keywords: stop, halt, emergency, abort, ruko, bas
  Word-boundary match, 100ms collision window
  Target latency: <200ms from word to ESTOP published ↓

(if no ESTOP)
Deepgram Nova-2 Streaming STT (WebSocket, en-IN)
  is_final=false → check_partial() for ESTOP keywords only
  is_final=true AND speech_final=true → pass to normaliser ↓

normaliser.py
  lowercase, filler word removal, punctuation normalisation
  simple alias expansion for clearly unambiguous cases only ↓

Multi-tool detection:
  Multiple tools in transcript → TTS: 'One at a time. Which first — {A} or {B}?' ↓

Groq API Intent Parser (llama-3.1-8b-instant, temperature 0.0, JSON mode)
  output: {tool, action, confidence}
  destination NOT in Groq output — hardcoded 'user_handover' in planner ↓

Intent Clarity Check:
  Clear (confidence >= 0.8) → Runtime voice consistency check → Auth gate
  Ambiguous (confidence < 0.8) → Dialogue Manager (LangGraph) ↓

Runtime Voice Consistency Check
  Lightweight d-vector similarity, logged-in user only ↓

ValidatedIntent published → /validated_intent → planner_node
```

### normaliser.py — Scope

```
Step 1 — Lowercase: 'Bring the SCALPEL' → 'bring the scalpel'
Step 2 — Strip fillers: 'um, can you please bring' → 'bring'
Step 3 — Punctuation strip: 'scissors,' → 'scissors'
Step 4 — Simple alias: 'bandage cloth' → 'bandage' (unambiguous only)
Step 5 — Multi-tool detect: 'scissors and scalpel' → flag for clarification
```

- Full contextual alias expansion ('the sharp one') stays in Groq — not hardcoded
- Multi-tool detection: if 2+ tool names in transcript → flag MULTI_TOOL before Groq call

---

## SECTION X — CONVERSATIONAL LAYER — LangGraph + Assistant Agent

> **SOFTWARE** — LangGraph dialogue management and assistant agent are Software. Bounded agentic layer for intent clarification and pre-auth interaction only.

### dialogue_node Operating Modes

| Mode | Activates When | Behaviour |
|---|---|---|
| ASSISTANT MODE | State = LOGGED_OUT and voice input detected | Groq-powered conversational agent. Handles ACARE self-introduction and guides auth flow. Professional, clinical, 1–3 sentences max. Model: llama-3.1-8b-instant. |
| DIALOGUE MODE | State = STANDBY / LISTENING / PROCESSING | LangGraph multi-node graph for intent clarity, clarification, context resolution, and interruption handling. Model: openai/gpt-oss-120b for complex clarification needing reasoning depth. |

### Session Memory Schema

```json
{
  "tools_fetched": [{"tool", "timestamp", "zone"}],
  "conversation_history": [turns],
  "current_task": {"tool", "status"},
  "pending_clarification": bool,
  "last_command": str
}
```

- conversation_history capped at 20 turns; older turns summarized to prevent Pi RAM exhaustion

### LangGraph Nodes

| Node | Trigger | Action |
|---|---|---|
| Intent Clarity Check | Every intent result | Routes to clear path or ambiguous path based on confidence and pronoun detection |
| Clarification Node | Ambiguous intent | Generates specific follow-up question using Groq LLM |
| Context Resolver | Pronoun or reference in command | Resolves 'it', 'that', 'the smaller one' using session memory |
| Interruption Handler | New command while task active | Safe pause, switch to new command or route to ESTOP |
| Dialogue Manager | All nodes route through | Final routing decision to auth gate |

### Handled Conversational Cases

| Input | Resolution |
|---|---|
| 'bring me something sharp' | Clarification: 'Do you mean a scalpel or scissors?' |
| 'actually bring the forceps instead' | Interruption handler: pause current task, switch target |
| 'bring it back' | Context resolver: 'it' = last tool in tools_fetched |
| 'the smaller one' | Context resolver: resolves against last ambiguous candidate set |
| 'I need that cutting thing' | Alias expansion + clarification if still ambiguous |
| 'bring me scissors and scalpel' | Multi-tool gate: 'One at a time. Which first?' |

---

## SECTION XI — VISION PIPELINE — NBV SEARCH & DETECTION

> **SOFTWARE** — All vision processing, YOLOv11 inference, NBV search, fake detection, 3D localisation, and hand tracking are Software running on Pi.

### Camera

YDLIDAR HP60C RGBD — wrist-mounted. Provides RGB frame and depth frame directly from hardware per capture. No stereo processing. Depth value read directly from depth frame at bounding box center pixel — no Open3D or point cloud processing needed.

### Sensor Roles — Final Assignments

**YDLIDAR HP60C (RGBD Camera, Wrist-Mounted) — Used for:**

- Tool detection during NBV search (YOLOv11 on RGB frames)
- 3D localisation of detected tools (depth pixel → 3D point)
- Fake object detection (texture variance + depth variance)
- Hand tracking during handover (MediaPipe Hands on RGB frames)
- Face detection/verification during login and handover (MediaPipe FaceDetection + MobileNet)

**YDLIDAR HP60C — NOT used for:**

- SLAM or navigation (robot is stationary)
- Person identification by LiDAR
- Continuous streaming (captures on demand, not always streaming)

**Camera capture protocol:**
```
Arm must be fully stationary before capture.
Capture 3 frames per viewpoint at ~2-3cm wrist offsets.
YOLOv11 inference on all 3 frames.
Merge detections via NMS across frames.
```

**YDLIDAR T-mini Plus (2D LiDAR, Base-Mounted at ~80cm) — Used for:**

- Person proximity detection only (torso-level 2D scan)
- Zone detection: > 600mm → Safe zone → velocity_scale = 1.0 / 400–600mm → Caution zone → velocity_scale = 0.5, SafetyAlert WARNING / < 400mm → Danger zone → SafetyAlert ESTOP immediately

**YDLIDAR T-mini Plus — NOT used for:**

- Tool detection (cannot — it's a 2D horizontal scan at 80cm, no colour/texture)
- Face detection or user identification
- NBV search strategy
- Finding the user for handover (it detects A torso, not WHOSE torso)

**LiDAR role at handover specifically:**
```
LiDAR detects "someone is in front of robot" → triggers camera face search.
LiDAR does NOT identify who the person is.
LiDAR does NOT detect hand or face.
During arm motion to handover zone: LiDAR proximity < 400mm → ESTOP immediately.
During actual handover (arm stationary): proximity monitoring continues.
  Person suddenly < 400mm during gripper release → ESTOP, tool held.
```

### Vision Node Startup

```
vision_node starts → publishes /vision_status: LOADING
YOLOv11 ONNX model loads into memory (several seconds on Pi)
Once loaded → publishes /vision_status: READY
planner_node checks /vision_status before accepting any commands
TTS: 'System initialising. Please wait.' if command arrives during LOADING
```

### Low Light Detection — Final Decision

Problem: YOLOv11 trained on well-lit images. Low-light surgical environments cause low confidence detections (thresholds dropping below 0.7).

**Solution (software only, no hardware addition):**

```python
# Step 1 — Preprocessing in vision_node before YOLOv11 inference:
# Apply CLAHE (Contrast Limited Adaptive Histogram Equalisation) to RGB frame.
import cv2
clahe = cv2.createCLAHE(clipLimit=2.0, tileGridSize=(8, 8))
# Convert to LAB, apply to L channel, convert back to BGR. Feed to YOLOv11.

# Step 2 — Adaptive confidence threshold:
mean_brightness = cv2.cvtColor(frame, cv2.COLOR_BGR2GRAY).mean()
if mean_brightness < 80:  # low light threshold, calibrated empirically
    confidence_threshold = 0.60
    temporal_consistency_required = 3  # viewpoints
    low_light_mode = True
else:
    confidence_threshold = 0.70
    temporal_consistency_required = 2  # viewpoints
    low_light_mode = False
```

- Low-light flag logged in every LogEvent when triggered: LogEvent.description includes "LOW_LIGHT_MODE" string
- Low-light threshold (mean_brightness < 80) calibrated empirically during setup

### Workspace Boundary Enforcement

All detections outside the defined workspace volume are discarded before any IK is attempted.

```
workspace: { xmin:-0.4, xmax:0.4, ymin:-0.3, ymax:0.3, zmin:0.0, zmax:0.5 }
```

### NBV Cold Start Strategy

- First boot or probability_map.yaml absent → uniform distribution across all zones
- Admin defines layout profile before exhibition: tool expected zones stored in probability_map.yaml
- Without admin prior, first demo run is slower — robot checks all zones before finding tool
- After first successful detection, the probabilistic map is updated via Bayesian inference, improving search efficiency for subsequent requests.

### NBV Timing Expectation — Per-Step Breakdown

| Step | Duration |
|---|---|
| Arm move + settle | ~1.0s |
| 3 frame captures (2–3cm wrist offsets) | ~0.3s |
| YOLOv11 ONNX inference ×3 | ~0.6–1.5s on Pi 5 |
| Merge + localise | ~0.1s |
| Total per viewpoint | ~2–3 seconds |
| Worst case (6–8 viewpoints, tool in last zone) | ~15–25 seconds |

If inference too slow on Pi 5 in practice, alternative options: reduced input resolution, model distillation to smaller variant, ONNX runtime instead of TFLite. Depends on testing results.

### Complete NBV Search Flow

```
Triggered by: planner_node publishes /vision_search_request
  {tool, reset_probability_map, priority_zones}

vision_node._execute_nbv_search():

1. Load probability_map for requested tool.
   If reset_probability_map == True → use uniform distribution for this search.
   If priority_zones not empty → boost those zones' probabilities × 2.0, normalise.

2. Sort viewpoints by P(tool|zone), highest first.
   Viewpoints are pre-defined arm poses stored in config (set during calibration).

3. For each viewpoint (loop):

   a. planner sends MOVE to embedded_interface_node → arm moves to viewpoint.
      Wait MotionFeedback.success.
      CRITICAL: do NOT capture until arm fully stationary.

   b. Estimate frame brightness (mean pixel value, grayscale).
      If mean < 80: apply CLAHE preprocessing. Set low_light_mode = True.
      Confidence threshold: 0.60 if low_light_mode, else 0.70.
      Temporal consistency required: 3 viewpoints if low_light_mode, else 2.

   c. Capture 3 frames at ~2-3cm wrist Z-offsets (tiny arm movements).
      Each frame: RGB + depth from HP60C.

   d. YOLOv11 ONNX inference on all 3 frames.
      Merge detections: NMS across 3 frames.
      Filter by confidence threshold (0.60 or 0.70 per above).
      Filter by workspace bounds: discard out-of-bounds detections.

   e. Fake object check (see fake object detection below).

   f. Filter to requested tool class only.
      Single detection → proceed.
      Multiple → highest confidence; tiebreak: closest to neutral arm position.

   g. Temporal consistency check:
      Same tool class at approximately same (x,y,z) (within 3cm) in required
      consecutive viewpoints → accepted even at confidence 0.65+.

   h. If found:
      depth_value = depth_frame[bbox_center_y][bbox_center_x]
      Convert to 3D using camera intrinsics + depth_value.
      tool_position_3D = (x, y, z) in robot frame.
      Store all other detections as detection_candidates in VisionResult
      for IK fallback use.
      Bayesian map update: probability[zone][tool] *= 1.5, clamp [0.05, 0.90], normalise.
      Passive update: all detected tools in viewpoint: probability *= 1.3, normalise.
      Publish /vision_result {found: true, tool, x, y, z, confidence, zone, candidates[]}.
      Return.

   i. If not found in this viewpoint:
      Bayesian map update: probability[zone][tool] *= 0.7, normalise, clamp.
      Continue to next viewpoint.

4. All viewpoints exhausted → not found.
   Publish /vision_result {found: false}.
   planner handles retry logic.
```

### Bayesian Probability Map Update — With Clamping

- Tool found in zone: probability[zone][tool] *= 1.5, then normalise
- Tool not found: probability[zone][tool] *= 0.7, then normalise
- Passive map update at every viewpoint for all detected tools: probability *= 1.3, normalise
- Clamping after every update: P = min(max(P, 0.05), 0.90) — prevents saturation, ensures no zone completely ignored
- On clean shutdown: serialise probability_map → probability_map.yaml
- On unclean boot: reload from yaml (may be slightly stale — acceptable)

This adaptive probabilistic mapping enables the system to learn instrument placement patterns over repeated sessions, reducing average search time.

### Fake Object Detection

Two independent signals. Both must trigger to flag as fake — reduces false rejections on shiny real tools.

```python
def is_fake(rgb_frame, depth_frame, bbox):
    x1, y1, x2, y2 = bbox
    roi_gray = cv2.cvtColor(rgb_frame[y1:y2, x1:x2], cv2.COLOR_BGR2GRAY)
    texture_var = cv2.Laplacian(roi_gray, cv2.CV_64F).var()
    depth_roi = depth_frame[y1:y2, x1:x2]
    depth_var = np.var(depth_roi[depth_roi > 0])
    return texture_var < TEXTURE_THRESHOLD and depth_var < DEPTH_THRESHOLD
```

Thresholds calibrated empirically during setup (20 real + 20 printed samples). Stored in thresholds.yaml — not hardcoded.

```
If depth unavailable:
  Fall back to texture check only.
  Log: DEPTH_UNAVAILABLE.
  Accept if texture_var >= TEXTURE_THRESHOLD (lower trust, logged).

If fake detected:
  TTS: "Object appears to be a reproduction. Command rejected."
  Log: FAKE_REJECTED.
  Skip to next detection candidate or next viewpoint.
```

### Hand Tracking — During Handover

- MediaPipe Hands runs on RGB camera frames during HANDOVER state only (not during vision search)
- Detects: hand_detected, is_open (3+ fingers extended), palm_up (fingers above wrist)
- Position (x, y, z) of palm center converted to robot coordinates
- Publishes /hand_status every camera frame during HANDOVER state
- **MediaPipe Hands and YOLOv11 do NOT run simultaneously** — planner ensures this. vision_node switches mode based on robot state.

### Depth Camera Failure Handling

- Depth unavailable during fake detection → fall back to texture check only; flag lower confidence; Log: DEPTH_UNAVAILABLE
- Depth unavailable during 3D localisation → TTS: 'Camera error. Please retry.'; State → STANDBY; Log: DEPTH_FAILURE

### Tool Not Found — Full Recovery Flow

```
All viewpoints exhausted ↓
TTS: 'Cannot locate {tool}. Can you confirm it is on the tray?'
  'Yes it is there' → re-run NBV once more from scratch
  'Try the left side' → context resolver maps to zone → re-run from that zone only
  'Never mind' → abort → STANDBY ↓

Second search fails:
TTS: 'Still unable to locate {tool}. Please check tray or use manual procedure.'
State → STANDBY
```

### IK Failure Recovery — Full Step-by-Step

```
Grasp point computed ↓ IK solver runs
  Solution found → proceed
  Fail (joint limit violation): Try alternate grasp orientation (rotate approach 90°)
    Solution found → proceed
    Still fails: Try next detection candidate (next highest confidence)
      No candidates left: TTS: 'Unable to reach the {tool}. Please reposition it.'
      State → STANDBY
```

---

## SECTION XII — TASK PLANNER PIPELINE

> **SOFTWARE** — planner_node orchestrates the full pick-and-place sequence. Does not implement motor control — sends commands via embedded_interface_node.

### Planner Architecture — Three Layers

```
Layer 1 — AGENTIC DECISION LAYER:
  Model: openai/gpt-oss-120b via Groq API.
  Reasoning level: "high" for recovery decisions, "low" for search strategy.
  Strict JSON schema output (guaranteed schema compliance, no parse errors).
  Proposes: search strategy, recovery actions, handover pose adjustments.
  CANNOT execute anything directly.
  Has deterministic fallbacks for every decision (LLM failure does not stop the robot).

Layer 2 — DETERMINISTIC SAFETY KERNEL:
  Pure Python, no external calls, no LLM.
  Validates every proposal from Layer 1.
  validate_move(): workspace bounds check + ESTOP check.
  validate_grasp(): force limit check.
  validate_handover(): session + safety severity check.
  validate_release(): 3-check gate (hand + voice required; face advisory).
  velocity_scale(): returns float based on safety severity.
  CANNOT be overridden. No exceptions.

Layer 3 — NODE COORDINATION:
  Publishes ROS2 commands. Subscribes to ROS2 feedback.
  All communication via typed topics (or std_msgs JSON fallback).
  Runs task pipeline in background thread (not blocking ROS2 callbacks).
```

### Retry Policy

```python
MAX_RETRIES = 3  # global constant, per failure type independently

# Failure types and their independent counters:
#   vision_search  — NBV search returned no result
#   grasp          — gripper force confirmation failed
#   ik_solve       — IK solver returned None
#   handover_face  — face verification failed at handover

# Rules:
# Each counter is independent. Grasp fail does not consume vision retry.
# On attempt N == MAX_RETRIES: TTS must warn user ("Last attempt...").
# After MAX_RETRIES exceeded: abort with clear user message, State → STANDBY.
# Exception: handover_face — attempt 3 is VOICE_HAND_ONLY fallback, not abort.
#   Handover never aborts on face failure alone. Voice + hand still required.
```

### Groq API Call Structure

```python
# Every LLM call follows this pattern:
response = groq_client.chat.completions.create(
    model="openai/gpt-oss-120b",
    messages=[
        {"role": "system", "content": PLANNER_SYSTEM_PROMPT + "\n\nReasoning: {high|low}"},
        {"role": "user",   "content": json.dumps(context_dict)}
    ],
    response_format=DECISION_SCHEMA,  # strict JSON schema
    temperature=0.1,                  # near-deterministic
    max_completion_tokens=512
)
decision = json.loads(response.choices[0].message.content)
```

### Decision JSON Schema (Strict Mode)

```json
{
  "type": "json_schema",
  "json_schema": {
    "name": "planner_decision",
    "strict": true,
    "schema": {
      "type": "object",
      "properties": {
        "decision_type": {
          "type": "string",
          "enum": ["SEARCH_STRATEGY","VISION_RECOVERY","GRASP_RECOVERY",
                   "IK_RECOVERY","HANDOVER_RECOVERY","ABORT"]
        },
        "reasoning": {"type": "string"},
        "action": {
          "type": "string",
          "enum": [
            "RETRY_UNIFORM_SEARCH",
            "ASK_USER_CONFIRM_LOCATION",
            "ABORT_TOOL_NOT_FOUND",
            "RETRY_GRASP_REPOSITION",
            "RETRY_GRASP_FORCE_INCREASE",
            "ABORT_GRASP_FAILED",
            "RETRY_IK_ALTERNATE_ORIENTATION",
            "RETRY_IK_NEXT_CANDIDATE",
            "ABORT_IK_FAILED",
            "HANDOVER_Z_UP",
            "HANDOVER_Z_DOWN",
            "HANDOVER_VOICE_HAND_ONLY",
            "SEARCH_PRIORITY_ZONES"
          ]
        },
        "tts_message": {"type": "string"},
        "params": {
          "type": "object",
          "properties": {
            "force_delta_n":         {"type": "number"},
            "z_offset_m":            {"type": "number"},
            "rotation_deg":          {"type": "number"},
            "priority_zones":        {"type": "array", "items": {"type": "string"}},
            "reset_probability_map": {"type": "boolean"}
          },
          "required": ["force_delta_n","z_offset_m","rotation_deg",
                       "priority_zones","reset_probability_map"],
          "additionalProperties": false
        }
      },
      "required": ["decision_type","reasoning","action","tts_message","params"],
      "additionalProperties": false
    }
  }
}
```

### Planner System Prompt

```
You are the agentic decision layer of ACARE — an Autonomous Clinical Assistance Robot
operating in a surgical environment. You orchestrate task recovery and search strategy
for a 6-DOF robotic arm that fetches sterile instruments for authenticated surgical staff.

HARD RULES:
- Never suggest bypassing authentication or safety checks.
- Never suggest moving outside workspace bounds.
- Never suggest gripper force above 10N.
- Only suggest actions from the allowed action enum.
- If uncertain, choose ABORT over unsafe continuation.
- Keep tts_message brief (1-2 sentences), professional, clinical tone.
- On final attempt (attempt == max_retries): tts_message MUST warn staff this is the last try.
- After all retries exhausted: tts_message must clearly state inability and suggest manual procedure.

Reasoning: {high|low}   ← injected per call
```

### CLASS: RetryCounters

```python
@dataclass
class RetryCounters:
    vision_search: int = 0
    grasp: int = 0
    ik_solve: int = 0
    handover_face: int = 0
```

**Methods:**
- `exhausted(failure_type: str) -> bool` — True if counter >= MAX_RETRIES
- `increment(failure_type: str)` — Increment named counter by 1
- `is_last_attempt(failure_type: str) -> bool` — True when current value == MAX_RETRIES - 1 (next is the last)

### CLASS: SafetyKernel — All Methods

#### `validate_move(target_pos, world) -> (bool, str)`

Checks (x,y,z) against workspace bounds. Checks ESTOP state. Returns (False, reason) if any check fails. Returns (True, "CRITICAL — velocity capped at 50%") if severity is CRITICAL but move is geometrically valid. Called by every arm move before the command is sent. Hard limits: xmin=-0.4, xmax=0.4, ymin=-0.3, ymax=0.3, zmin=0.0, zmax=0.5 (metres).

#### `validate_grasp(force_target, world) -> (bool, str)`

Rejects any force > 15N (ESTOP threshold). Warns but approves 10–15N range. Approves < 10N unconditionally. Called by every grasp command before sending. Note: Planner itself caps retry forces at 10N. Safety kernel is the final backstop.

#### `validate_handover(world) -> (bool, str)`

Rejects if no active session (active_user_id empty). Rejects if safety_severity is ESTOP or CRITICAL. Called before moving arm to handover zone.

#### `validate_release(world, face_verified, hand_detected, voice_confirmed) -> (bool, str)`

Hand detected AND voice confirmed are BOTH required. Face is advisory — if face_verified is False but the other two pass, returns (True, "FACE_SKIPPED — logged"). If hand or voice fails → returns (False, reason). Called immediately before RELEASE command is sent.

#### `velocity_scale(world) -> float`

Returns 0.5 if CRITICAL, 0.75 if WARNING, 1.0 if OK. Called by every arm move, multiplied with task_phase_scale before sending velocity_scale to embedded_interface_node.

### CLASS: AgenticPlanner — All Methods

#### `__init__(self, logger)`

Initialises Groq client (GROQ_API_KEY from env). Initialises user_profiles dict (user_id → UserProfile). Initialises time_patterns dict (hour → {tool: preferred_zone}).

#### `_call_llm(self, messages, reasoning_level) -> Optional[Dict]`

**Signature:** `_call_llm(messages: List[Dict], reasoning_level: str = "low") -> Optional[Dict]`

Calls openai/gpt-oss-120b with strict JSON schema. Injects reasoning level into system prompt. Returns parsed dict. Returns None on any exception (network error, parse error). Never raises — robot must not crash on LLM failure.

#### `propose_search_strategy(self, tool, user_id, current_hour, attempt_number) -> Dict`

**Signature:** `propose_search_strategy(tool: str, user_id: str, current_hour: int, attempt_number: int) -> Dict`

Called before the first NBV search attempt. Looks up user's preferred zone for this tool (from UserProfile.preferred_zones). Looks up time-based hint (from time_patterns[current_hour][tool]). Sends both as context to gpt-oss-120b with reasoning: low. Returns decision dict with action=SEARCH_PRIORITY_ZONES and priority_zones list. If LLM fails, returns deterministic fallback (empty priority_zones, use probability map default).

**Fallback (LLM failure):**
```python
{
    "decision_type": "SEARCH_STRATEGY",
    "action": "SEARCH_PRIORITY_ZONES",
    "reasoning": "LLM unavailable — using probability map default",
    "tts_message": f"Searching for {tool}.",
    "params": {"priority_zones": [], "reset_probability_map": False,
               "force_delta_n": 0.0, "z_offset_m": 0.0, "rotation_deg": 0.0}
}
```

#### `propose_vision_recovery(self, tool, attempt, world) -> Optional[Dict]`

**Signature:** `propose_vision_recovery(tool: str, attempt: int, world: WorldState) -> Optional[Dict]`

Called after each failed NBV search. `attempt` is 1, 2, or 3. Returns None if attempt > MAX_RETRIES. Sends context to gpt-oss-120b with reasoning: high. On attempt 3 (final), injects instruction to warn staff in tts_message. Returns None after MAX_RETRIES — planner interprets this as abort.

**Deterministic fallbacks (LLM failure):**
```
attempt 1 → action: RETRY_UNIFORM_SEARCH, reset_probability_map: True
             tts: "Searching again for {tool}."
attempt 2 → action: ASK_USER_CONFIRM_LOCATION
             tts: "I still cannot find the {tool}. Can you confirm it is on the tray?"
attempt 3 → action: ABORT_TOOL_NOT_FOUND (final search attempt before abort)
             tts: "Last attempt — searching one final time for the {tool}."
```
After attempt 3 returns and search still fails: planner calls `_abort_task("I was unable to find the {tool}. Please check the tray or use manual procedure.")`

#### `propose_grasp_recovery(self, tool, attempt, world) -> Optional[Dict]`

**Signature:** `propose_grasp_recovery(tool: str, attempt: int, world: WorldState) -> Optional[Dict]`

Called after each failed gripper force confirmation. Reasoning: high. On attempt 3, tts warns staff. Returns None if attempt > MAX_RETRIES.

**Deterministic fallbacks:**
```
attempt 1 → action: RETRY_GRASP_REPOSITION, rotation_deg: 15.0, force_delta_n: 0.0
             tts: "Adjusting grip on {tool}. Retrying."
attempt 2 → action: RETRY_GRASP_FORCE_INCREASE, force_delta_n: 1.0 (→ 4.0N total)
             tts: "Retrying grasp of {tool} with adjusted force."
attempt 3 → action: RETRY_GRASP_FORCE_INCREASE, force_delta_n: 2.0 (→ 5.0N total, max)
             tts: "Last attempt to grasp the {tool}. Please ensure it is correctly positioned."
```
After attempt 3 fails: planner calls `_abort_task("Unable to grasp the {tool}. Please reposition it and try again.")`

#### `propose_ik_recovery(self, tool, attempt, context, world) -> Optional[Dict]`

**Signature:** `propose_ik_recovery(tool: str, attempt: int, context: TaskContext, world: WorldState) -> Optional[Dict]`

Called after each IK solve failure. Passes `context.alternate_orientation_tried` and `len(context.detection_candidates)` to LLM. Reasoning: high. Returns None if attempt > MAX_RETRIES.

**Deterministic fallbacks:**
```
attempt 1, alternate not tried → action: RETRY_IK_ALTERNATE_ORIENTATION, rotation_deg: 90.0
                                   tts: "Adjusting approach angle for {tool}."
attempt 1/2, has candidates   → action: RETRY_IK_NEXT_CANDIDATE
                                   tts: "Trying alternate position for {tool}."
attempt 3, final              → tts: "Last attempt to reach the {tool}."
no candidates remain          → action: ABORT_IK_FAILED
                                   tts: "Unable to reach the {tool}. Please reposition it and try again."
```

#### `propose_handover_face_recovery(self, user_name, tool, attempt, current_z) -> Dict`

**Signature:** `propose_handover_face_recovery(user_name: str, tool: str, attempt: int, current_z: float) -> Dict`

Called after each face verification failure during handover. Reasoning: low. Returns Dict always (never None — handover never aborts on face failure). On attempt 3 → always returns HANDOVER_VOICE_HAND_ONLY regardless of LLM.

**Deterministic fallbacks:**
```
attempt 1 → action: HANDOVER_Z_UP, z_offset_m: +0.05
             tts: "Please look at the camera."
attempt 2 → action: HANDOVER_Z_DOWN, z_offset_m: -0.05
             tts: "Please face the camera directly."
attempt 3 → action: HANDOVER_VOICE_HAND_ONLY
             tts: "Face verification unavailable. Proceeding with voice and hand confirmation only."
```

#### `learn_from_success(self, context, user_id)`

**Signature:** `learn_from_success(context: TaskContext, user_id: str)`

After successful handover. Updates UserProfile.preferred_zones[tool] = zone_found. Updates time_patterns[current_hour][tool] = zone_found. Both are in-memory only (not persisted across restarts in current implementation — persistence is a future addition).

#### `learn_height_adjustment(self, user_id, command)`

**Signature:** `learn_height_adjustment(user_id: str, command: str)`

Called when user says "lower" or "higher" during handover. Adjusts UserProfile.handover_z_offset by ±0.05m. Clamps to [-0.15, +0.15] (±15cm range). Stored in user_profiles dict (in-memory).

#### `get_handover_pose(self, user_id) -> Tuple[float, float, float]`

**Signature:** `get_handover_pose(user_id: str) -> Tuple[float, float, float]`

Returns (HANDOVER_ZONE.x, HANDOVER_ZONE.y, HANDOVER_ZONE.z + user_z_offset). If no profile for user_id, z_offset = 0.0. SafetyKernel.validate_move() is called by the caller after this returns.

### CLASS: PlannerNode — All Methods

#### `__init__(self)`

Calls super().__init__('planner_node'). Initialises WorldState, TaskContext, AgenticPlanner, SafetyKernel. Creates MutuallyExclusiveCallbackGroup for motion feedback (so heartbeat doesn't share thread with vision/TTS). Creates all publishers and subscribers. Initialises threading.Event for motion and vision wait patterns. Logs startup with model name and MAX_RETRIES.

#### `_on_validated_intent(self, msg)`

Entry point for all fetch commands. Checks world.current_task is None (reject if already tasked). Sets world.current_task = msg.tool. Starts `_execute_fetch_task` in background daemon thread. Returns immediately to not block ROS2 callbacks.

#### `_on_validated_intent_json(self, msg: String)`

Fallback when acare_msgs not available. Parses JSON from std_msgs String. Same logic as above.

#### `_on_vision_result(self, msg)`

Stores vision result in `self._vision_result` dict. Sets `self._vision_event` (threading.Event). Unblocks `_execute_vision_search` which is waiting on this event.

#### `_on_motion_feedback(self, msg)`

Stores `msg.success` in `self._motion_success`. Sets `self._motion_event`. Unblocks `_send_arm_move` which is waiting on this event. Runs in MutuallyExclusiveCallbackGroup.

#### `_on_safety_alert(self, msg)`

Updates `world.safety_severity`. If ESTOP → calls `_handle_estop(msg.reason)`. If CRITICAL or WARNING → logs only (planner adjusts velocity on next move via `SafetyKernel.velocity_scale()`).

#### `_on_hand_status(self, msg)`

Stores latest hand status in `self._latest_hand_status` dict. Used by `_wait_for_hand_detect()` polling loop.

#### `_on_robot_state(self, msg)`

Updates `world.robot_state` and `world.active_user_id` from state_manager.

#### `_execute_fetch_task(self, tool, user_id, user_name)`

**Signature:** `_execute_fetch_task(tool: str, user_id: str, user_name: str)` — runs in background thread

Full task pipeline. Records pipeline_start. Resets TaskContext. Calls each phase in sequence. On any phase failure → calls `_abort_task()`. On full success → calls `learn_from_success()`, logs, speaks, transitions to STANDBY.

**Sequence:**
```python
_check_world_state()           # abort if fail
_send_gripper_open()           # abort if fail
_phase_vision_search()         # abort if all 3 attempts fail
_phase_grasp()                 # abort if all 3 attempts fail
_phase_handover()              # safe_deposit if fail
learn_from_success()
_log_success()
_speak("Handover complete. Is there anything else?")
_transition_state('STANDBY')
```

#### `_check_world_state(self) -> bool`

Returns False (with TTS) if: safety_severity == ESTOP, vision_status == LOADING or ERROR, network_ok == False. Returns True if all clear.

#### `_phase_vision_search(self, tool, user_id) -> bool`

**Signature:** `_phase_vision_search(tool: str, user_id: str) -> bool`

Outer loop for all vision search attempts. Runs up to MAX_RETRIES iterations.

**Loop body:**
```
iteration 1:
  propose_search_strategy() → get priority_zones, reset_probability_map
  _speak(strategy.tts_message)
  _execute_vision_search(tool, reset_probability_map, priority_zones)
  Found → return True

iteration 2:
  propose_vision_recovery(tool, attempt=2, world)
  _speak(recovery.tts_message)
  If action == ASK_USER_CONFIRM_LOCATION: time.sleep(5.0)
  _execute_vision_search(tool, reset_probability_map, priority_zones)
  Found → return True

iteration 3:
  propose_vision_recovery(tool, attempt=3, world)
  _speak(recovery.tts_message)  ← "Last attempt..."
  _execute_vision_search(tool, reset_probability_map, priority_zones)
  Found → return True

All 3 fail → return False
```

#### `_phase_grasp(self, tool) -> bool`

**Signature:** `_phase_grasp(tool: str) -> bool`

Outer loop for all grasp attempts. Runs up to MAX_RETRIES iterations.

**Loop body per iteration:**
```
iteration 1: force_target=3.0, rotation_deg=0.0
iterations 2-3: propose_grasp_recovery() → get force_delta_n, rotation_deg
                force_target = 3.0 + force_delta_n, clamped to 10.0N max
                _speak(recovery.tts_message)

Each iteration:
  SafetyKernel.validate_grasp(force_target, world)
  Compute pregrasp = grasp_point + (0, 0, +0.05)
  SafetyKernel.validate_move(pregrasp, world)
  vel = SafetyKernel.velocity_scale(world) × 0.8
  _send_arm_move(pregrasp, vel)
  SafetyKernel.validate_move(grasp_point, world)
  vel = SafetyKernel.velocity_scale(world) × 0.5
  _send_arm_move(grasp_point, vel, rotation_offset_deg)
  _send_gripper_grasp(force_target)
  time.sleep(0.5)
  Check world.gripper_force >= 1.0N → return True
  Else → continue loop

All 3 fail → return False
```

#### `_resolve_ik(self, target_pos, tool) -> Optional[List[float]]`

**Signature:** `_resolve_ik(target_pos: Tuple[float,float,float], tool: str) -> Optional[List[float]]`

Calls ik_solver.solve(target_pos). On failure, calls propose_ik_recovery() and executes action (alternate orientation, next candidate). Returns joint_angles list or None after MAX_RETRIES.

**Loop body:**
```
call ik_solver.solve(target_pos, rotation_offset_deg)
If solution found → return joint_angles

propose_ik_recovery(tool, attempt, context, world)
_speak(recovery.tts_message)

RETRY_IK_ALTERNATE_ORIENTATION:
  rotation_offset_deg = recovery.params.rotation_deg
  context.alternate_orientation_tried = True
  Retry ik_solver.solve with new rotation

RETRY_IK_NEXT_CANDIDATE:
  Pop next from context.detection_candidates
  target_pos = (candidate.x, candidate.y, candidate.z)
  context.grasp_point = target_pos

ABORT_IK_FAILED:
  return None

After MAX_RETRIES → return None
```

#### `_phase_handover(self, tool, user_id, user_name) -> bool`

**Signature:** `_phase_handover(tool: str, user_id: str, user_name: str) -> bool`

Full handover protocol. Moves arm to handover pose. Runs 3 substates: face verify (with recovery), hand detect, voice confirm. Calls SafetyKernel.validate_release() before release. Returns True on successful handover, False on timeout or safety rejection.

**Sequence:**
```
_transition_state('HOLDING')
get_handover_pose(user_id) → handover_pose
SafetyKernel.validate_handover(world)
SafetyKernel.validate_move(handover_pose, world)
_send_arm_move(handover_pose, velocity_scale)
_transition_state('HANDOVER')
_speak("{tool} ready. Please face the camera.")
handover_start = time.monotonic()
current_z = handover_pose[2]

FACE_VERIFY loop (max 3):
  _wait_for_face_verify(user_id, timeout=8.0)
  If found → face_verified=True, break
  propose_handover_face_recovery(user_name, tool, attempt, current_z)
  _speak(recovery.tts_message)
  Execute Z adjustment (validate + move) or set face_skipped=True

Timeout check: (time.monotonic() - handover_start) > HANDOVER_TIMEOUT_S → return False

HAND_DETECT:
  _speak("Please place your open palm under the gripper.")
  _wait_for_hand_detect(timeout=10.0)
  If not detected: _speak("Please open your palm."), _wait_for_hand_detect(timeout=8.0)
  Dynamic palm tracking: update arm target from /hand_status (x,y,z) in real-time
  Handle "lower"/"higher" voice commands → learn_height_adjustment()

VOICE_CONFIRM:
  _speak("Say 'take' to receive.")
  _wait_for_voice_confirm(user_id, timeout=5.0)

SafetyKernel.validate_release(world, face_verified, hand_ok, voice_ok)
If rejected → _speak("Handover verification failed. Returning tool to tray.") → return False

If face_skipped: _log_event("FACE_VERIFY_SKIPPED", tool)
_send_gripper_release()
time.sleep(0.5)
world.arm_holding = False
return True
```

#### `_execute_vision_search(self, tool, reset_probability_map, priority_zones) -> bool`

**Signature:** `_execute_vision_search(tool: str, reset_probability_map: bool, priority_zones: List[str]) -> bool`

Publishes /vision_search_request. Clears and waits on `_vision_event` (timeout 30s). On result received: checks found=True and confidence >= 0.7. Stores grasp_point and detection_candidates in context. Returns True/False.

#### `_safe_deposit(self, tool)`

**Signature:** `_safe_deposit(tool: str = '')`

Controlled move to SAFE_DROP_ZONE. Always validates move first. velocity_scale=0.3. Releases gripper. Clears world.arm_holding. Transitions to STANDBY. Logs SAFE_DEPOSIT event. Called when: handover fails, ESTOP while holding, network fail while holding.

#### `_handle_estop(self, reason)`

If world.arm_holding → calls `_safe_deposit()` first (controlled deposit). Then transitions to ESTOP state. Clears current_task.

#### `_wait_for_face_verify(self, user_id, timeout) -> bool`

Polls for face verification result from auth_node. In production: subscribes to /auth_result, checks face_verified field and user_id match. Timeout returns False.

#### `_wait_for_hand_detect(self, timeout) -> bool`

Polls `self._latest_hand_status` every 100ms. Returns True when hand_detected=True AND is_open=True AND palm_up=True, all simultaneously. Returns False on timeout.

#### `_wait_for_voice_confirm(self, user_id, timeout) -> bool`

Polls for voice confirmation from voice_node. Checks keyword ("take"/"yes") AND d-vector consistency for user_id. Timeout returns False.

#### `_send_arm_move(self, position, velocity_scale, rotation_offset_deg) -> bool`

**Signature:** `_send_arm_move(position: Tuple[float,float,float], velocity_scale: float = 1.0, rotation_offset_deg: float = 0.0) -> bool`

Calls `_resolve_ik(position)` (activate when hardware params available). Constructs ArmCommand with command="MOVE", joint_angles, velocity_scale. Publishes to /arm_command. Clears _motion_event. Waits on _motion_event (timeout 15s). Returns True if MotionFeedback.success.

**Task phase velocity scales:**
```
Pre-grasp approach: × 0.8
Grasp descent: × 0.5
Move to handover: × 0.6
Safe deposit: × 0.3
All others: × 1.0
```

#### `_send_gripper_open(self) -> bool`

Publishes GripperCommand {command="RELEASE", force_target=0.0}. Waits 600ms for physical open time (~500ms per spec).

#### `_send_gripper_grasp(self, force_target) -> bool`

Publishes GripperCommand {command="GRASP", force_target}. Returns True (force confirmation done by caller after sleep).

#### `_send_gripper_release(self) -> bool`

Publishes GripperCommand {command="RELEASE", force_target=0.0}. Waits 600ms for physical open/drop.

#### `_speak(self, text)`

Publishes text to /tts_request (String). voice_node handles routing to Edge TTS / Kokoro / pyttsx3.

#### `_transition_state(self, target)`

Updates world.robot_state. Publishes StateTransition to /state_transition → state_manager receives and enforces.

#### `_abort_task(self, message)`

Logs error. Speaks message. Logs TASK_ABORTED event. Clears world.current_task. Sends arm to neutral (velocity_scale=0.5). Transitions to STANDBY.

#### `_log_success(self)`

Logs full latency breakdown: vision_search_ms, motion_ms, total_task_ms, all retry counters (vision, grasp, ik, face). Publishes LogEvent to /log_event.

#### `_log_event(self, event_type, tool, description)`

Constructs LogEvent with all fields. Publishes to /log_event → log_node writes to SQLite.

### Complete Task Flow

```
ValidatedIntent {tool, action} + Authenticated Identity ↓
Record pipeline_start_time ↓
Check /vision_status — wait if LOADING, TTS: 'System initialising. Please wait.' ↓
Tool Registry Lookup → map tool name + aliases → YOLOv11 class label ↓
destination = 'user_handover'  # always — not inferred by Groq ↓
get_world_state() — check safety_severity, network_ok, arm_holding ↓
Gripper: send GRIPPER_OPEN, wait for force sensor = 0 ↓
Record vision_start_time
Vision NBV Search → /vision_search_request → wait for /vision_result
Record vision_search_ms = now - vision_start_time ↓
Grasp point received → IK solver (DLS, max 100 iterations)
IK failure → recovery flow (see Vision section) ↓
Record motion_start_time
ArmCommand: MOVE_TO_PREGRASP (5cm above tool) → wait MotionFeedback.success ↓
ArmCommand: GRASP {force_target: 3.0N} → wait MotionFeedback.success ↓
Gripper force sensor confirmation:
  Confirmed → proceed
  Failed after 3 attempts → TTS: 'Grasp failed. Please reposition the {tool}.'
  ArmCommand: MOVE_NEUTRAL → State → STANDBY ↓
ArmCommand: MOVE_TO_HANDOVER_ZONE → wait MotionFeedback.success
Record motion_ms = now - motion_start_time ↓
TTS: '{tool} ready. Please face the camera.' ↓
HANDOVER — Three-Check Verification (managed by handover.py module):
  Substate FACE_VERIFY: continuous face check every 0.5s, threshold 0.78
  Substate HAND_DETECT: wait for open palm in handover zone via MediaPipe
  Substate VOICE_CONFIRM: TTS 'Say take to receive.' → voice check → RELEASE ↓
Force sensor drops to zero → collection confirmed ↓
Record total_task_ms = now - pipeline_start_time
Log event {tool, staff_id, timestamp, zone_found, grasp_attempts, success,
           voice_e2e_ms, vision_search_ms, motion_ms, total_task_ms}
Update probability_map (zone where tool found) ↓
TTS: 'Handover complete. Is there anything else?'
ArmCommand: MOVE_NEUTRAL → State → STANDBY
```

### World State Snapshot — Folded into planner_node

```python
def get_world_state():
    return {
        "robot_state":      current_state,
        "safety_severity":  latest_safety_alert.severity,
        "vision_confidence": latest_vision_result.confidence,
        "network_ok":       deepgram_latency < threshold,
        "arm_holding":      gripper_force > 0
    }
```

Planner calls get_world_state() before every major decision point — before vision search, before grasp, before handover release, after any safety alert.

### Tool Registry — Alias Handling

```python
TOOL_REGISTRY = {
    "cream":        {"yolo_class": "cream",        "aliases": ["lotion", "ointment", "topical"]},
    "scissors":     {"yolo_class": "scissors",     "aliases": ["medical scissors", "surgical scissors", "the smaller one", "cutting tool"]},
    "oximeter":     {"yolo_class": "oximeter",     "aliases": ["oxymeter", "pulse ox", "oxygen monitor", "SPO2"]},
    "plaster":      {"yolo_class": "plaster",      "aliases": ["bandaid", "strip", "adhesive strip"]},
    "forceps":      {"yolo_class": "forceps",      "aliases": ["surgical forceps", "tweezers", "clamps", "graspers"]},
    "thermometer":  {"yolo_class": "thermometer",  "aliases": ["temp probe", "temperature tool"]},
}
```

### IK Solver — Implementation

- Method: Damped Least Squares (DLS) / Levenberg-Marquardt
- DLS handles near-singular configurations without diverging — critical for 6-DOF arm near joint limits
- damping_factor: 0.05, max_iterations: 100, position_tolerance: 1mm, orientation_tolerance: 0.01 rad
- Joint limit enforcement: hard clamp at each iteration
- If solution not found within max_iterations → IK failure → recovery flow

### Complete planner_node.py Reference Implementation

```python
#!/usr/bin/env python3
# acare_planner/planner_node.py
# Spec Reference: Section XII (Task Planner Pipeline)
#
# CENTRAL ORCHESTRATOR — Agentic Task Planner for ACARE
#
# The planner_node is the BRAIN. It owns:
#   - Full task lifecycle (fetch → search → grasp → handover)
#   - World state snapshot (safety, network, vision, arm status)
#   - Agentic decision layer (adaptive search, recovery, learning)
#   - Cross-node coordination (voice, vision, auth, safety, embedded)
#
# SAFETY GUARANTEE: All agentic proposals are validated by the
# DeterministicSafetyKernel before execution. Agentic layer proposes,
# safety kernel approves. No exceptions.
#
# RETRY POLICY (per failure type, max 3 each):
#   Vision search  → 3 attempts, escalating strategy, then abort
#   Grasp          → 3 attempts, repositioning + force adjustment, then abort
#   IK solve       → 3 attempts, orientation + candidate fallback, then abort
#   Handover face  → 3 attempts, Z-height search, then voice+hand fallback (not abort)
#   On final attempt → TTS warns user before attempting ("Last try...")
#   After 3 fails  → clear TTS message, STANDBY
#
# AGENTIC MODEL: gpt-oss-120b via Groq (Reasoning: high for recovery,
#                                        Reasoning: low for strategy hints)
#
# Architecture:
#   ┌─────────────────────────────────────────────┐
#   │  AGENTIC DECISION LAYER (proposes)           │
#   │  • gpt-oss-120b, strict JSON schema          │
#   │  • Adaptive NBV search strategy              │
#   │  • Per-failure-type recovery planning        │
#   │  • User preference learning                  │
#   │  • Reasoning: high/low per decision type     │
#   └─────────────────────────────────────────────┘
#              ↓ (proposals validated)
#   ┌─────────────────────────────────────────────┐
#   │  DETERMINISTIC SAFETY KERNEL (enforces)      │
#   │  • Workspace bounds: HARD CLAMP              │
#   │  • Velocity/force/temp: HARD LIMITS          │
#   │  • ESTOP: IMMEDIATE, NO OVERRIDE             │
#   │  • Auth: MUST PASS, NO BYPASS                │
#   └─────────────────────────────────────────────┘
#              ↓ (validated commands)
#   ┌─────────────────────────────────────────────┐
#   │  NODE COORDINATION (executes)                │
#   │  • Publishes to /arm_command                 │
#   │  • Subscribes to /motion_feedback            │
#   │  • Manages /vision_search_request            │
#   │  • Handles /hand_status, /safety_alert       │
#   └─────────────────────────────────────────────┘

import rclpy
from rclpy.node import Node
from rclpy.executors import MultiThreadedExecutor
from rclpy.callback_groups import MutuallyExclusiveCallbackGroup
import threading
import time
import json
import os
from datetime import datetime
from typing import Optional, Dict, List, Tuple
from dataclasses import dataclass, field
from groq import Groq

# ROS2 messages
try:
    from acare_msgs.msg import (
        ValidatedIntent, VisionResult, VisionSearchRequest,
        ArmCommand, GripperCommand, MotionFeedback,
        HandStatus, SafetyAlert, RobotState, LogEvent,
        StateTransition
    )
    MSGS_OK = True
except ImportError:
    MSGS_OK = False
    print("[planner_node] acare_msgs not available — using std_msgs fallbacks")

from std_msgs.msg import String

# =============================================================================
# CONFIGURATION
# =============================================================================

WORKSPACE = {
    'xmin': -0.4, 'xmax': 0.4,
    'ymin': -0.3, 'ymax': 0.3,
    'zmin': 0.0,  'zmax': 0.5,
}

HANDOVER_ZONE   = {'x': 0.0, 'y': 0.4, 'z': 0.1}
SAFE_DROP_ZONE  = {'x': 0.0, 'y': 0.35, 'z': 0.05}

NETWORK_FAIL_HOLD_THRESHOLD_S   = 5.0
HANDOVER_TIMEOUT_S              = 30.0
SESSION_INACTIVITY_TIMEOUT_S    = 300.0

MAX_RETRIES = 3  # Universal cap — applies per failure type independently

# Groq model for agentic layer
AGENTIC_MODEL = "openai/gpt-oss-120b"

# Groq model for intent parsing (unchanged)
INTENT_MODEL = "llama-3.1-8b-instant"

# =============================================================================
# DATA CLASSES
# =============================================================================

@dataclass
class WorldState:
    robot_state: str       = 'STANDBY'
    safety_severity: str   = 'OK'       # OK | WARNING | CRITICAL | ESTOP
    vision_status: str     = 'READY'    # LOADING | READY | ERROR
    network_ok: bool       = True
    arm_holding: bool      = False
    gripper_force: float   = 0.0
    active_user_id: str    = ''
    active_user_name: str  = ''
    last_command_time: float = 0.0
    current_task: Optional[str] = None

@dataclass
class RetryCounters:
    """
    Per-failure-type retry counters.
    Each is independent — a grasp fail does not consume a vision retry.
    All capped at MAX_RETRIES (3).
    """
    vision_search: int   = 0   # NBV search returned no result
    grasp: int           = 0   # Gripper failed to confirm hold
    ik_solve: int        = 0   # IK solver could not find solution
    handover_face: int   = 0   # Face verification failed at handover

    def exhausted(self, failure_type: str) -> bool:
        return getattr(self, failure_type, 0) >= MAX_RETRIES

    def increment(self, failure_type: str):
        current = getattr(self, failure_type, 0)
        setattr(self, failure_type, current + 1)

    def is_last_attempt(self, failure_type: str) -> bool:
        """True when the NEXT attempt will be the final one."""
        return getattr(self, failure_type, 0) == MAX_RETRIES - 1

@dataclass
class TaskContext:
    tool_requested: str  = ''
    tool_canonical: str  = ''
    yolo_class: str      = ''
    search_start_time: float = 0.0
    vision_search_ms: int    = 0
    motion_ms: int           = 0
    total_task_ms: int       = 0
    zone_found: str          = ''
    grasp_point: Tuple[float, float, float] = (0.0, 0.0, 0.0)
    pregrasp_point: Tuple[float, float, float] = (0.0, 0.0, 0.0)
    retries: RetryCounters = field(default_factory=RetryCounters)
    # IK recovery state
    alternate_orientation_tried: bool = False
    detection_candidates: List[Dict]  = field(default_factory=list)

@dataclass
class UserProfile:
    user_id: str            = ''
    name: str               = ''
    handover_z_offset: float = 0.0     # learned from lower/higher
    preferred_zones: Dict[str, str] = field(default_factory=dict)  # tool → zone
    last_login: str         = ''

# =============================================================================
# DETERMINISTIC SAFETY KERNEL — Absolute Authority
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

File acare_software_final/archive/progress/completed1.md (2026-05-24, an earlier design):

# ACARE — Raspberry Pi 5 Setup & Progress Log

**Date completed:** May 10, 2026  
**Pi:** Raspberry Pi 5 8GB  
**OS:** Ubuntu Server 24.04.4 LTS (aarch64)  
**Kernel:** Linux 6.8.0-1052-raspi  
**IP:** 192.168.1.72  
**Username:** acare / Password: acare1234  
**WiFi:** Airtel_Sarsou

---

## 1. OS & System Setup

- Flashed Ubuntu Server 24.04.4 LTS (64-bit) using Raspberry Pi Imager v2.0.7
- SSH enabled with password authentication from first boot
- WiFi pre-configured in Imager (Airtel_Sarsou)
- Passwordless SSH set up from laptop (SSH key installed)
- `unattended-upgrades` disabled — prevents background apt from dropping SSH
- `needrestart` masked — prevents service restarts mid-apt-session
- System updated: `sudo apt update && sudo apt upgrade -y`

---
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

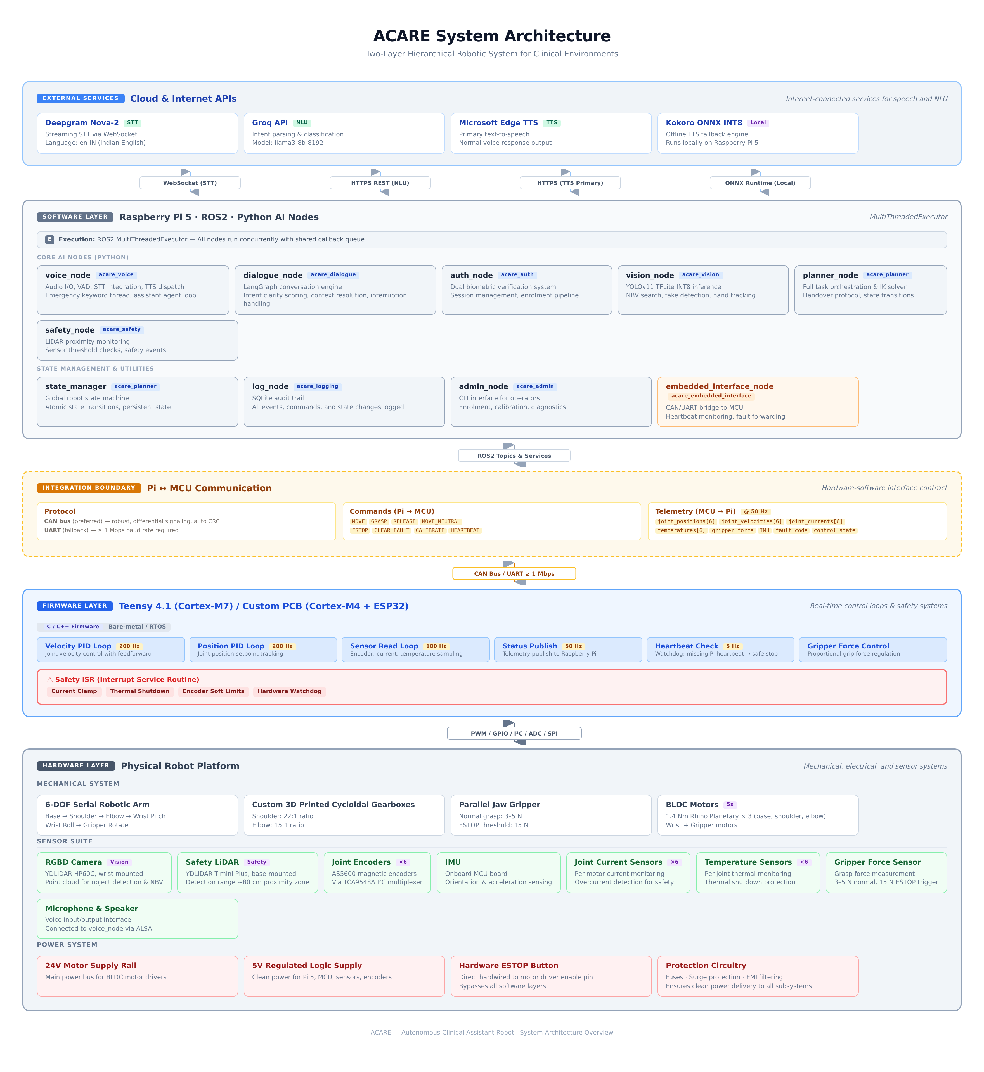
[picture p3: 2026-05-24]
acare_software_final/docs/diagrams/acare_system_architecture.png

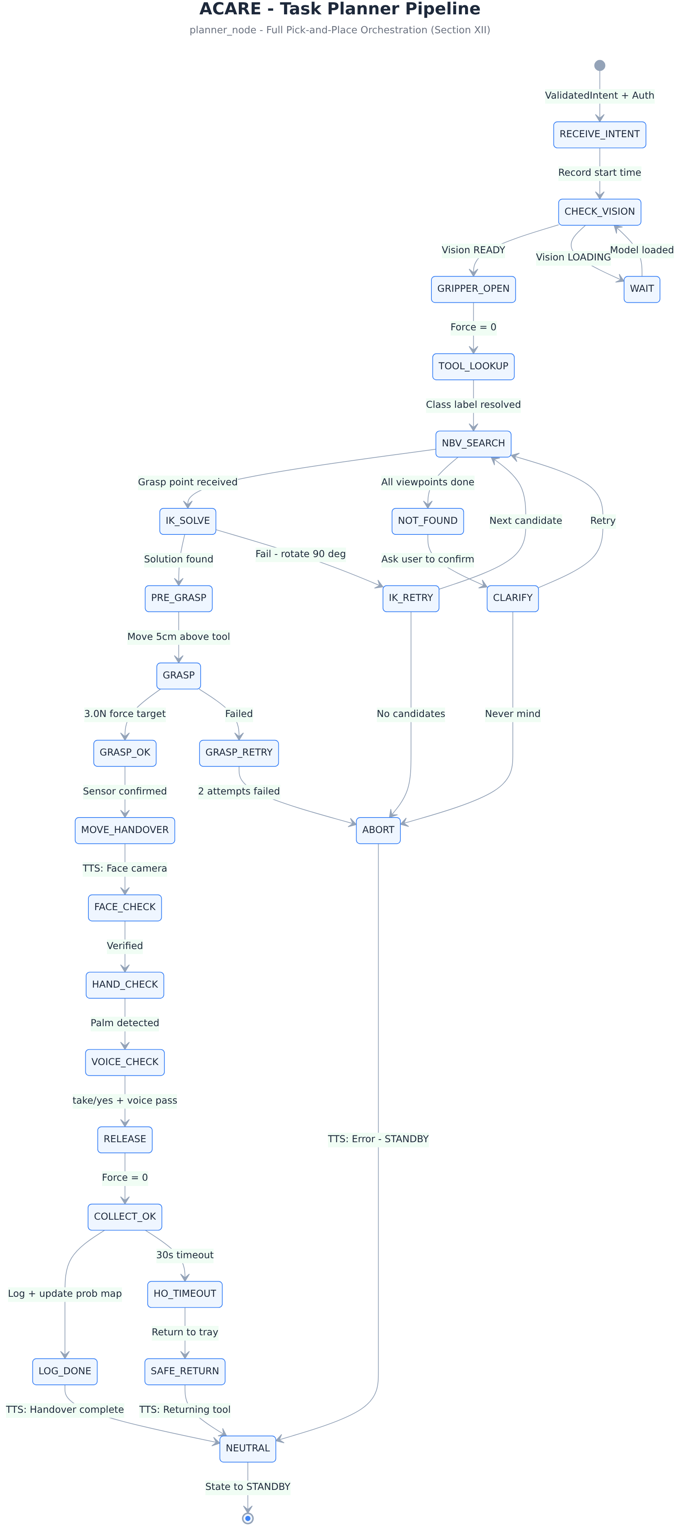
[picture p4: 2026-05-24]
acare_software_final/docs/diagrams/10_task_planner_pipeline.png

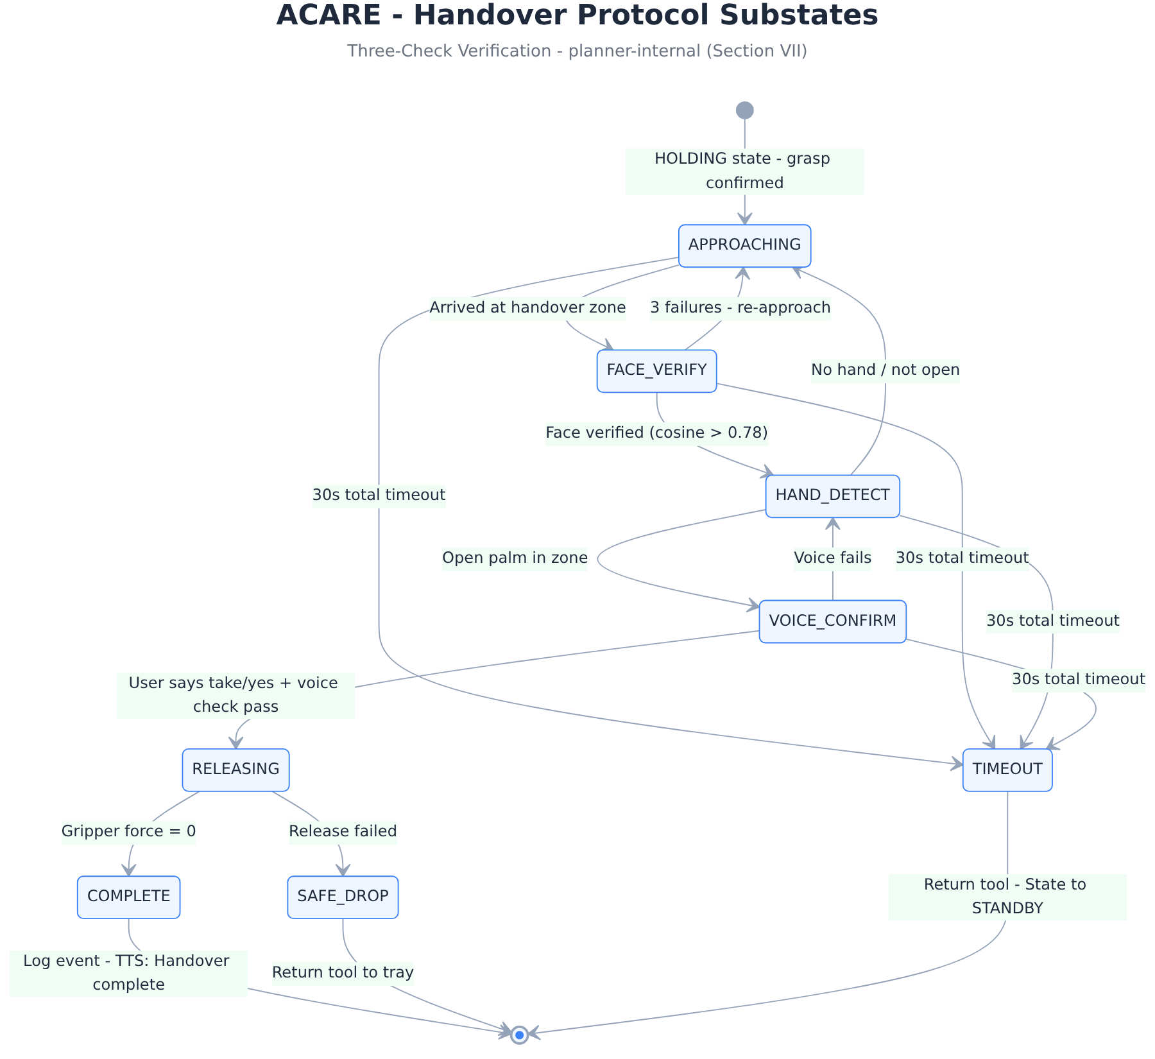
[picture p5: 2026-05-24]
acare_software_final/docs/diagrams/05_handover_substates.png

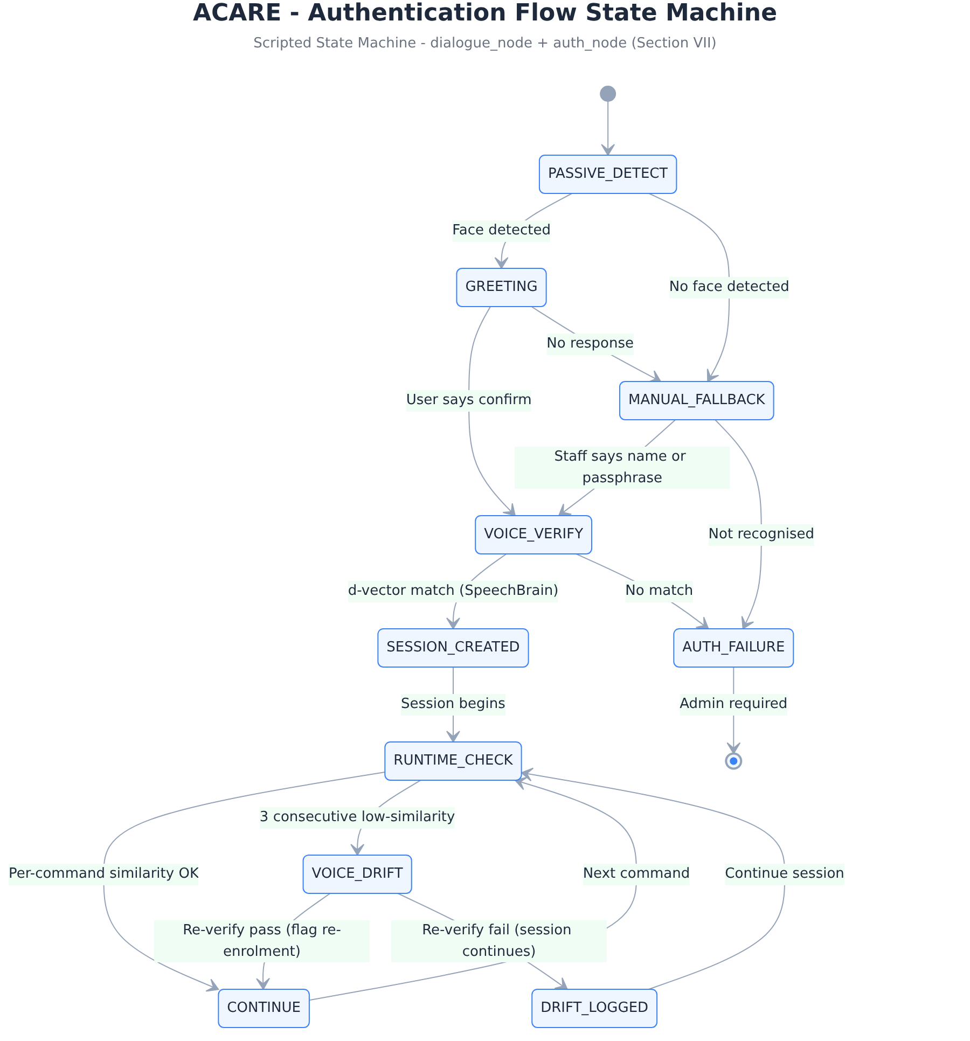
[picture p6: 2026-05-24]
acare_software_final/docs/diagrams/04_auth_login_flow.png

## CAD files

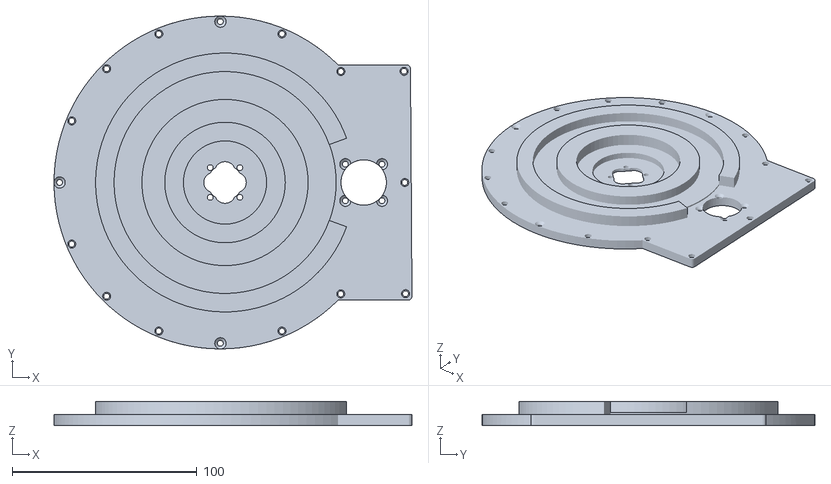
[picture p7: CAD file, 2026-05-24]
acare_software_final/simulation/src/acaresim_final/acaresim/src/urdf_assembly_6dof_description/meshes/base_link.stl
193.6 x 180.0 x 13.0

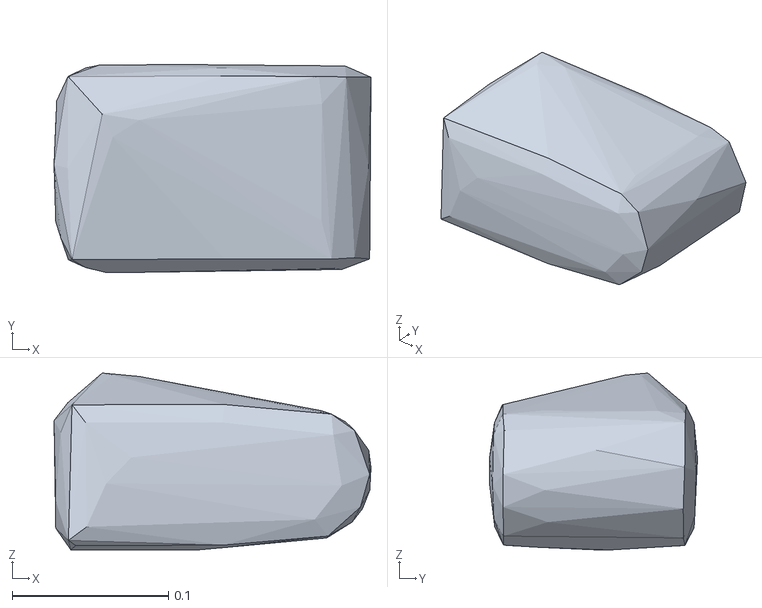
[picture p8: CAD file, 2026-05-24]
acare_software_final/simulation/src/irb120_ros2_gazebo/meshes/collision/link_4.stl
0.203 x 0.133 x 0.113

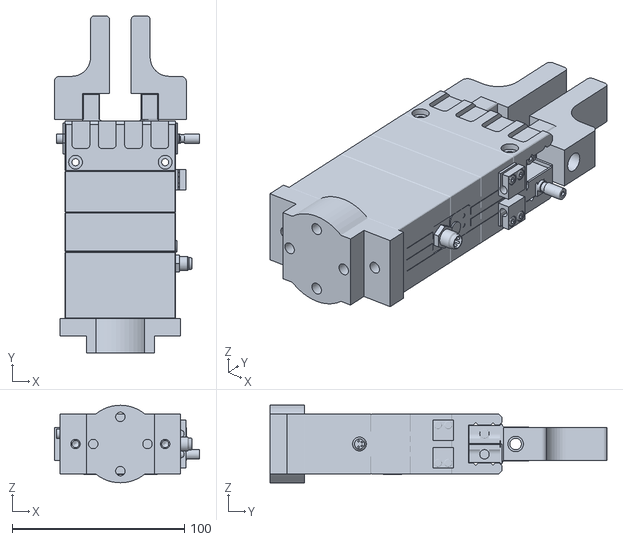
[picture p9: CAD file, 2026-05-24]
acare_software_final/simulation/src/irb120_ros2_gazebo/meshes/egp64/Schunk Gripper - Cranfield Robotics.STL
84.3 x 195.6 x 45.0

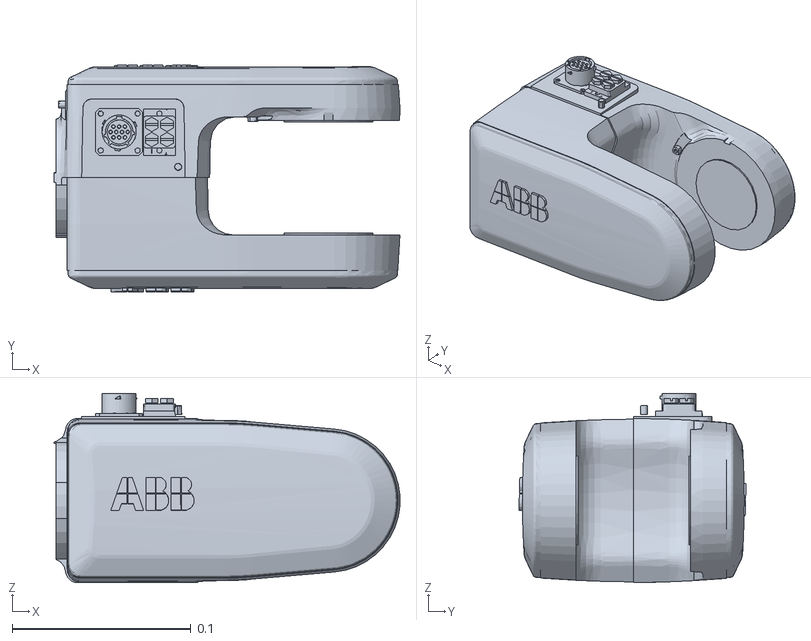
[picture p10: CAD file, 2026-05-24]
acare_software_final/simulation/src/irb120_ros2_gazebo/meshes/visual/link_4.stl
0.193 x 0.127 x 0.106

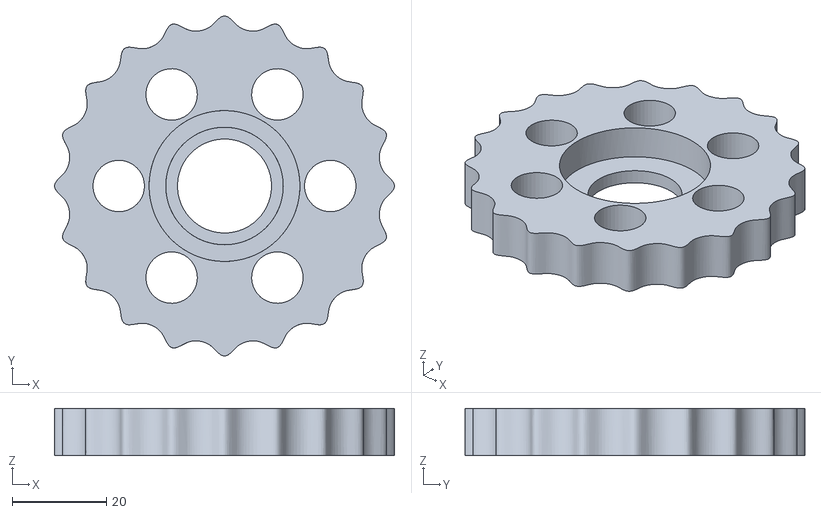
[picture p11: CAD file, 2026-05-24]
acare_software_final/simulation/src/acaresim_final/acaresim/src/urdf_assembly_6dof_description/meshes/20_1_cycloid_2.stl
72.3 x 72.3 x 10.0

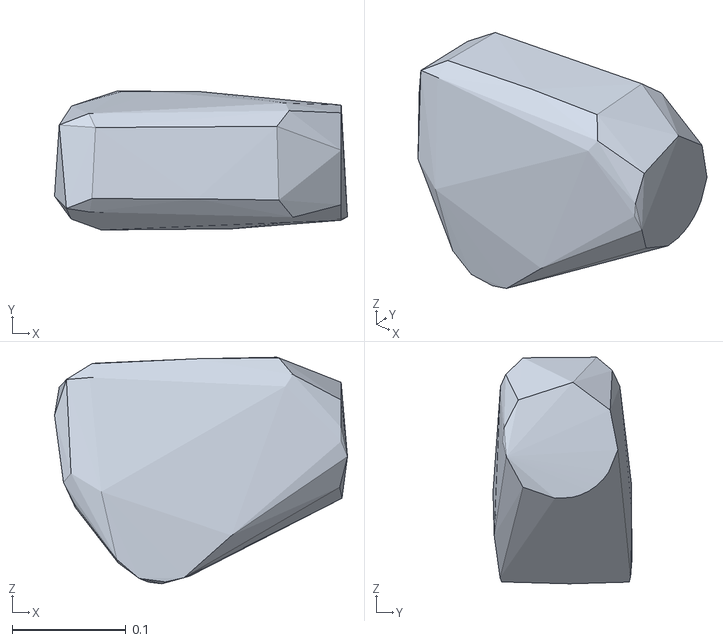
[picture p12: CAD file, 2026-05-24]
acare_software_final/simulation/src/irb120_ros2_gazebo/meshes/collision/link_3.stl
0.257 x 0.122 x 0.199

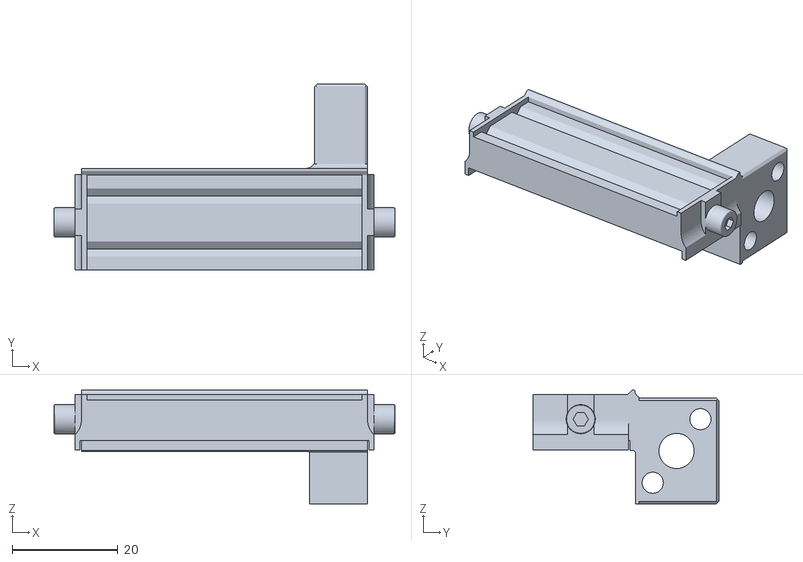
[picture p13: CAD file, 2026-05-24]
acare_software_final/simulation/src/irb120_ros2_gazebo/meshes/egp64/Schunk Gripper - LEFT FINGER BASE.STL
64.4 x 35.1 x 21.5

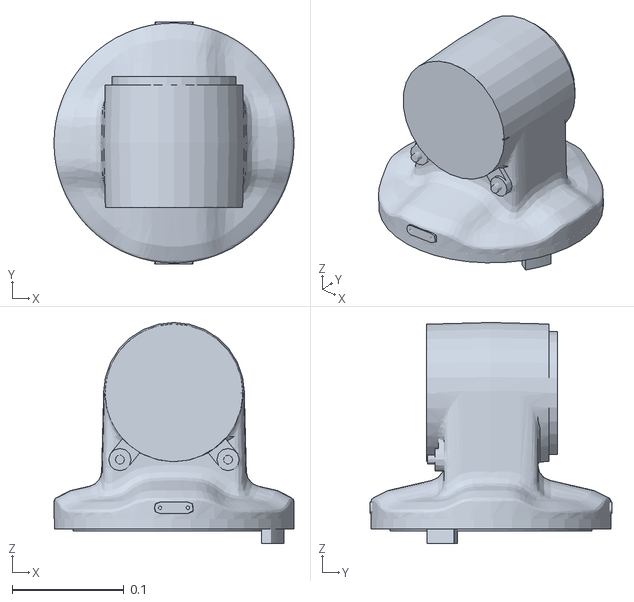
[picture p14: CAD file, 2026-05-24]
acare_software_final/simulation/src/irb120_ros2_gazebo/meshes/visual/link_1.stl
0.215 x 0.217 x 0.198

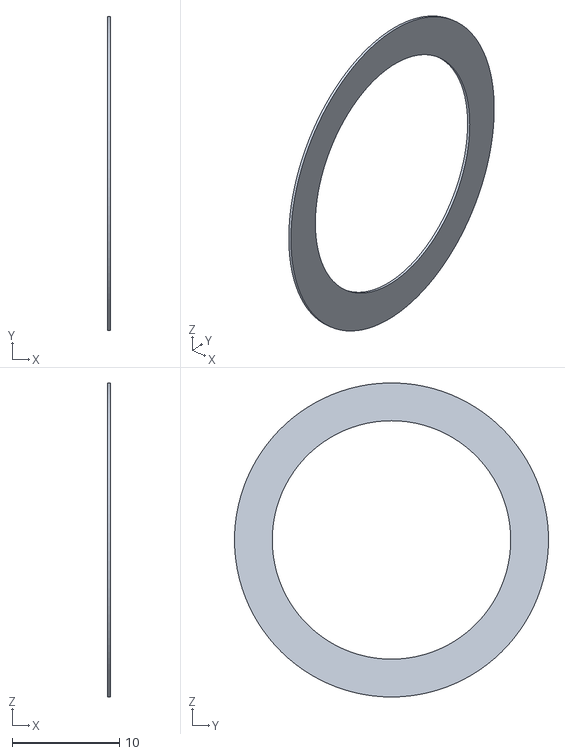
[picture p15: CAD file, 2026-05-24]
acare_software_final/simulation/src/acaresim_final/acaresim/src/urdf_assembly_6dof_description/meshes/6804ZZ Shield1.stl
0.242 x 29.2 x 29.2

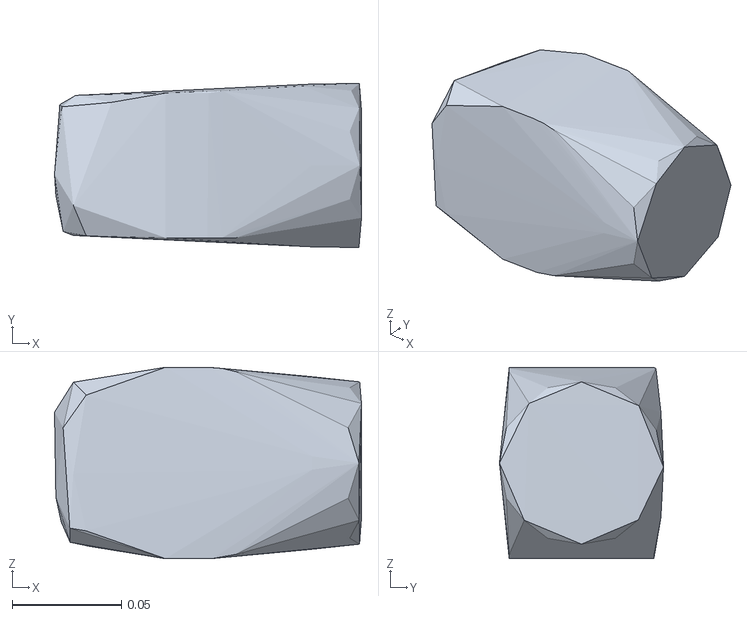
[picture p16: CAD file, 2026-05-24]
acare_software_final/simulation/src/irb120_ros2_gazebo/meshes/collision/link_5.stl
0.141 x 0.0752 x 0.0877

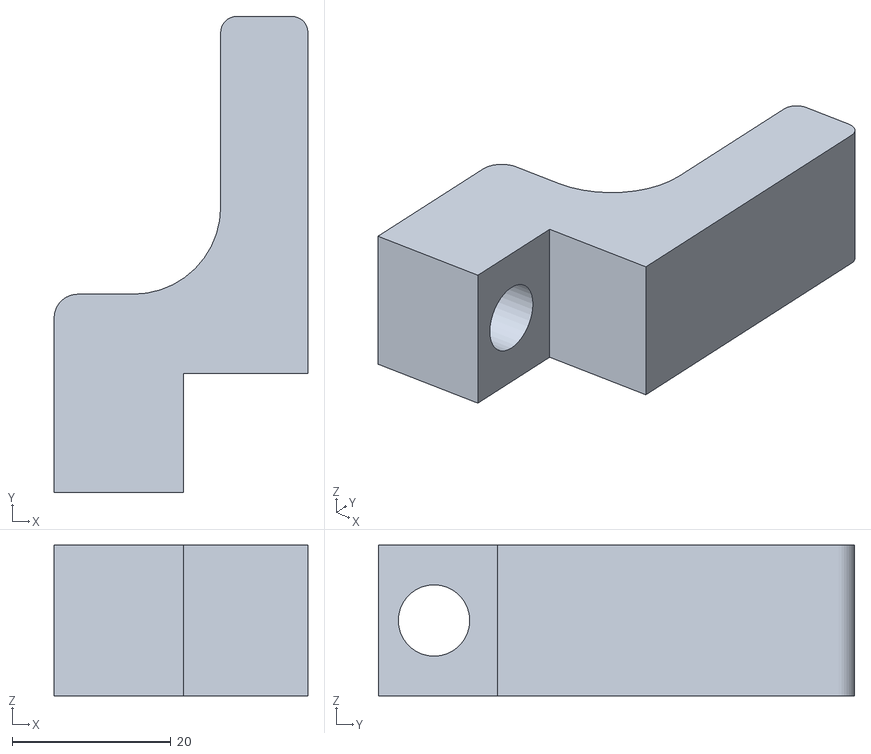
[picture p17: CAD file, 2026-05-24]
acare_software_final/simulation/src/irb120_ros2_gazebo/meshes/egp64/Schunk Gripper - RIGHT FINGER.STL
32.0 x 60.0 x 19.0

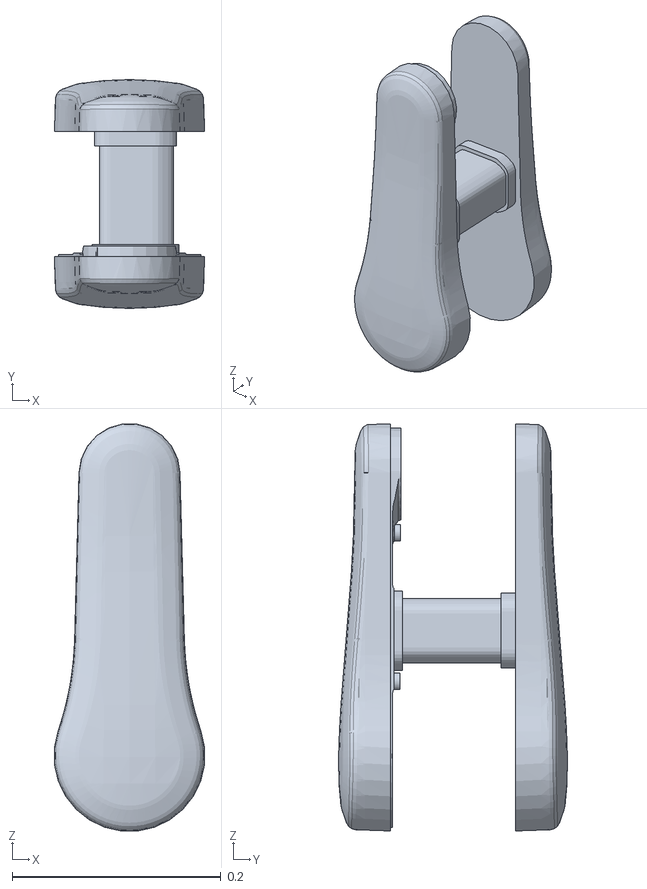
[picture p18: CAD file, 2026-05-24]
acare_software_final/simulation/src/irb120_ros2_gazebo/meshes/visual/link_2.stl
0.144 x 0.219 x 0.39

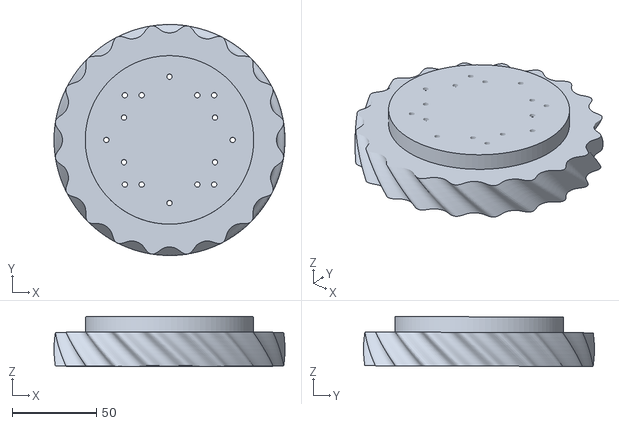
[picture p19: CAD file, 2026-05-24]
acare_software_final/simulation/src/acaresim_final/acaresim/src/urdf_assembly_6dof_description/meshes/eccentric_15_1_2_v1_1.stl
137.0 x 137.0 x 29.7

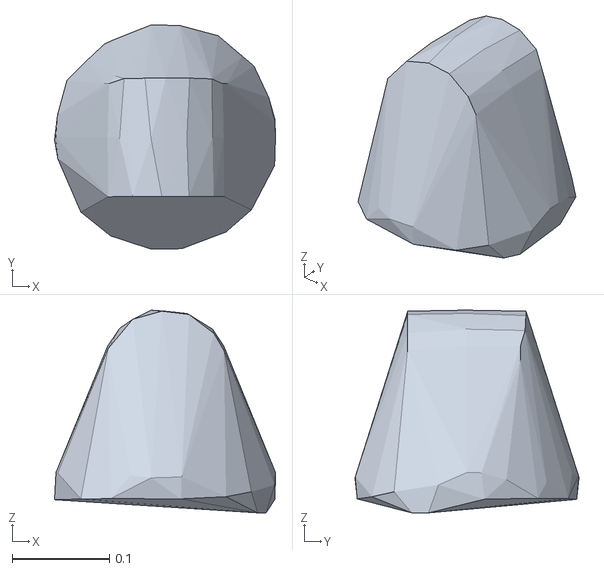
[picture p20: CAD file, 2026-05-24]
acare_software_final/simulation/src/irb120_ros2_gazebo/meshes/collision/link_1.stl
0.227 x 0.23 x 0.208

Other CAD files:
acare_software_final/simulation/src/acaresim_final/acaresim/build/urdf_assembly_6dof_description/meshes/roller_base.stl
acare_software_final/simulation/src/acaresim_final/acaresim/install/urdf_assembly_6dof_description/share/urdf_assembly_6dof_description/meshes/gripper_limb_1_finger_v1_2.stl
acare_software_final/simulation/src/acaresim_final/acaresim/install/urdf_assembly_6dof_description/share/urdf_assembly_6dof_description/meshes/20_1_cycloid_2.stl
acare_software_final/simulation/src/acaresim_final/acaresim/install/urdf_assembly_6dof_description/share/urdf_assembly_6dof_description/meshes/base_link.stl
acare_software_final/simulation/src/acaresim_final/acaresim/build/urdf_assembly_6dof_description/meshes/20_1_cycloid_1.stl
acare_software_final/simulation/src/acaresim_final/acaresim/build/urdf_assembly_6dof_description/meshes/20_1_cycloid_2.stl
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

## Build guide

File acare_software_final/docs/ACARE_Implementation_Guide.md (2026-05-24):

# ACARE — Implementation Guide & Spec Validation

> **Scope:** Perception pipeline (full) + Software pipeline (full) + Spec corrections.  
> Voice node (`voice_node.py`, VAD, ASR, keyword monitor) is excluded from this document.  
> Hardware is fixed. Raspberry Pi 5 (8 GB) is the compute platform.

---

## Table of Contents

1. [Spec Validation Summary](#1-spec-validation-summary)
2. [Perception Pipeline](#2-perception-pipeline)
   - [P0 — hp60c_camera_node.py (Camera Driver)](#p0--hp60c_camera_nodepy-camera-driver)
   - [P1 — vision_node.py (Orchestrator)](#p1--vision_nodepy-orchestrator)
   - [P2 — YOLOv11 ONNX INT8 Inference](#p2--yolov11-onnx-int8-inference)
   - [P3 — NBV Search (nbv_search.py)](#p3--nbv-search-nbv_searchpy)
   - [P4 — Fake Object Detection (fake_detector.py)](#p4--fake-object-detection-fake_detectorpy)
   - [P5 — 3D Localisation (localiser.py)](#p5--3d-localisation-localiserpy)
   - [P6 — Hand Tracking (hand_tracker.py)](#p6--hand-tracking-hand_trackerpy)
   - [P7 — Bayesian Probability Map](#p7--bayesian-probability-map)
3. [Software Pipeline](#3-software-pipeline)
   - [S1 — normaliser.py](#s1--normaliserpy)
   - [S2 — auth_node.py](#s2--auth_nodepy)
   - [S3 — dialogue_node.py (LangGraph)](#s3--dialogue_nodepy-langgraph)
   - [S4 — planner_node.py](#s4--planner_nodepy)
   - [S5 — ik_solver.py](#s5--ik_solverpy)
   - [S6 — handover.py](#s6--handoverpy)
   - [S7 — state_manager.py](#s7--state_managerpy)
   - [S8 — safety_node.py](#s8--safety_nodepy)
   - [S9 — embedded_interface_node (C++)](#s9--embedded_interface_node-c)
   - [S10 — log_node.py](#s10--log_nodepy)
   - [S11 — admin_cli.py](#s11--admin_clipy)
   - [S12 — supervisor.py](#s12--supervisorpy)
4. [Configuration Files](#4-configuration-files)
5. [ROS2 Package Structure & acare_msgs](#5-ros2-package-structure--acare_msgs)
6. [Full Dependencies](#6-full-dependencies)

---

## 1. Spec Validation Summary

The table below lists every issue found in the original spec, what is wrong, and what the correct implementation must be.

| # | Location in Spec | Issue | Correction |
|---|---|---|---|
| 1 | Section VIII, XV, XXI | TTS listed as **Google Cloud TTS WaveNet** for normal responses | **Wrong.** Use `edge-tts` (`pip install edge-tts`). Microsoft Edge TTS — free, no API key, no quota. Indian English voices: `en-IN-NeerjaNeural` (female) or `en-IN-PrabhatNeural` (male). Section VIII correctly says Edge TTS — Section XV contradicts it. Section XV is the error. |
| 2 | Section VII, XXIII | Speaker verification described as **"d-vector embeddings"** | **Wrong terminology.** d-vectors/x-vectors are the older TDNN architecture. Use SpeechBrain **ECAPA-TDNN**: `speechbrain/spkrec-ecapa-voxceleb`. EER ~0.8% vs 3.2% for x-vector. More robust to OT background noise. ~17 MB model. Same `cosine_similarity` interface. |
| 3 | Section XI, XXI | YOLOv11 described as **TFLite INT8** | **Suboptimal.** Benchmarks on Pi 5 show ONNX Runtime INT8 achieves ~77 ms/frame (13 FPS) for YOLOv11n at 640×640. TFLite INT8 is comparable in speed but ONNX tooling is cleaner, better debuggable, and the Ultralytics export pipeline produces cleaner ONNX. Use `onnxruntime` with ONNX INT8. Export: `model.export(format='onnx', int8=True, imgsz=320)`. Use 320×320 not 640×640 on Pi 5. |
| 4 | Section VII | Face verification described as **"MobileNet-based face embedding"** — vague | Use **InsightFace `buffalo_sc`** bundle: MobileNet RetinaFace detection + MobileFaceNet ArcFace. 512-D embeddings, ~24 ms on CPU, `pip install insightface`. For passive always-on face detection (not recognition), keep MediaPipe FaceDetection — it is lighter and sufficient for triggering the login flow. |
| 5 | Section XI | HP60C described as having a **ROS2 driver via ydlidar_ros2_driver** | `ydlidar_ros2_driver` is for LiDAR devices only. The HP60C is a depth camera and needs the **YDLIDAR HP60C SDK** with a custom ROS2 wrapper that publishes `sensor_msgs/Image` for RGB and depth. Write `hp60c_camera_node.py` using the SDK's Python bindings. |
| 6 | Section XV | **pyttsx3 listed for safety but also "reinitialise per call on Windows"** | The Windows reinitialisation bug is a dev-machine issue only. On Pi (Linux), pyttsx3 works without reinitialisation. Keep the Windows workaround in dev environment only — do not carry it into Pi deployment code. |
| 7 | Section XIX, admin_cli | Google TTS API key command in admin_cli | Remove `set-api-key --service google-tts`. Replace with nothing — `edge-tts` requires no key. Keep `--service deepgram` and `--service groq` only. |
| 8 | Section XXIII status | YOLO listed as **"TFLite INT8 export ready"** | Re-export as ONNX INT8 instead. Run export on training machine, copy `.onnx` to Pi. |
| 9 | Section II | Shoulder gearbox ratio listed as **20:1** in some spec versions | **Confirmed 22:1** (hardware team). The correct ratio is **22:1 shoulder, 15:1 elbow**. Use 22:1 in all DH parameter calculations and system.yaml comments. |

**Items that are correct and validated:**
- Silero VAD — correct, still best lightweight local VAD.
- Deepgram Nova-2 streaming WebSocket — correct, best accuracy for en-IN.
- Groq `llama3-8b-8192` JSON mode at temperature 0.0 — correct for intent parsing.
- MediaPipe Hands for handover — correct, best free option.
- MediaPipe FaceDetection for passive detection — correct.
- LangGraph for dialogue — correct.
- DLS/Levenberg-Marquardt IK — correct method.
- Bayesian probability map with clamping — correct.
- Fake detection dual-signal (Laplacian + depth variance) — correct.
- YDLIDAR T-mini Plus for safety LiDAR via `ydlidar_ros2_driver` — correct (this IS a LiDAR device).
- pyttsx3 for ESTOP/safety TTS — correct (zero latency, offline).
- Kokoro ONNX INT8 as offline TTS fallback — correct.
- SQLite for audit logging — correct.
- CAN/UART for Pi ↔ Teensy — correct.

---

## 2. Perception Pipeline

All perception code lives in `acare_vision/`. The five files are:
`vision_node.py`, `nbv_search.py`, `fake_detector.py`, `localiser.py`, `hand_tracker.py`.

---

### P0 — hp60c_camera_node.py (Camera Driver)

> ⚠️ **MISSING FROM ORIGINAL GUIDE.** This is the first thing needed for all vision work. Without it, `vision_node.py` has no camera to call.

The HP60C is a depth camera — **not** a LiDAR. `ydlidar_ros2_driver` does not support it. You need a custom ROS2 node that wraps the YDLIDAR HP60C SDK and publishes RGB + depth frames as ROS2 topics.

**What it publishes:**
- `/camera/rgb` (`sensor_msgs/Image`, BGR8) — RGB frame
- `/camera/depth` (`sensor_msgs/Image`, 16UC1, values in mm) — depth frame
- `/camera/camera_info` (`sensor_msgs/CameraInfo`) — intrinsics (after calibration)

```python
# acare_vision/hp60c_camera_node.py
# Spec Reference: Section XI (Camera Interface)
#
# Wraps the YDLIDAR HP60C SDK Python bindings and publishes
# RGB + depth frames as ROS2 sensor_msgs/Image topics.
#
# SDK install: follow YDLIDAR HP60C SDK README — copy .so/.dll to system path
# Python bindings: from the SDK's python/ directory
#
# NOTE: The HP60C SDK Python bindings are not on PyPI.
# You must build them from the SDK source on the Pi.

import rclpy
from rclpy.node import Node
from sensor_msgs.msg import Image, CameraInfo
from std_msgs.msg import Header
import numpy as np
import threading
import time

# HP60C SDK import — adjust path after SDK installation on Pi
# The SDK provides a Python wrapper around the C++ library
try:
    import hp60c_sdk as sdk   # [FILL_AFTER_SDK_INSTALL — actual module name from SDK]
    SDK_AVAILABLE = True
except ImportError:
    SDK_AVAILABLE = False

class HP60CCameraNode(Node):
    """
    ROS2 wrapper for YDLIDAR HP60C RGBD camera.
    Publishes RGB and depth frames at the camera's native rate (~30 FPS).
    vision_node.py calls capture() directly via node reference — this node
    also publishes to topics for any other subscribers.
    """

    def __init__(self):
        super().__init__('hp60c_camera_node')

        # Publishers
        self.rgb_pub   = self.create_publisher(Image, '/camera/rgb',   10)
        self.depth_pub = self.create_publisher(Image, '/camera/depth', 10)
        self.info_pub  = self.create_publisher(CameraInfo, '/camera/camera_info', 10)

        # Latest frames — held in memory for direct capture() calls
        self._latest_rgb   = None
        self._latest_depth = None
        self._lock = threading.Lock()

        if not SDK_AVAILABLE:
            self.get_logger().error('HP60C SDK not found. Camera node running in stub mode.')
            self._stub_mode = True
        else:
            self._stub_mode = False
            self._init_camera()

        # Publish loop at ~30 FPS
        self.create_timer(1.0 / 30.0, self._publish_frame)
        self.get_logger().info('HP60C camera node started')

    def _init_camera(self):
        """Open the HP60C device via SDK."""
        # [FILL_AFTER_SDK_INSTALL — exact API depends on SDK version]
        # Typical pattern:
        #   self.camera = sdk.HP60C()
        #   self.camera.open(device_index=0)
        #   self.camera.set_resolution(640, 480)   # or 1280x720 — check SDK docs
        #   self.camera.start_stream()
        self.camera = None   # placeholder
        self.get_logger().warn('HP60C SDK init: [FILL_AFTER_SDK_INSTALL]')

    def _publish_frame(self):
        """Capture one frame pair and publish to ROS2 topics."""
        rgb, depth = self._capture_raw()
        if rgb is None or depth is None:
            return

        with self._lock:
            self._latest_rgb   = rgb
            self._latest_depth = depth

        stamp = self.get_clock().now().to_msg()
        header = Header()
        header.stamp = stamp
        header.frame_id = 'camera_link'

        # Publish RGB
        rgb_msg = Image()
        rgb_msg.header = header
        rgb_msg.height, rgb_msg.width = rgb.shape[:2]
        rgb_msg.encoding = 'bgr8'
        rgb_msg.step = rgb_msg.width * 3
        rgb_msg.data = rgb.tobytes()
        self.rgb_pub.publish(rgb_msg)

        # Publish depth (uint16, mm)
        depth_msg = Image()
        depth_msg.header = header
        depth_msg.height, depth_msg.width = depth.shape[:2]
        depth_msg.encoding = '16UC1'
        depth_msg.step = depth_msg.width * 2
        depth_msg.data = depth.astype(np.uint16).tobytes()
        self.depth_pub.publish(depth_msg)

    def _capture_raw(self) -> tuple:
        """
        Capture one RGB + depth frame pair from the HP60C.
        Returns (rgb_bgr_uint8, depth_uint16_mm) numpy arrays, or (None, None) on error.
        """
        if self._stub_mode or self.camera is None:
            # Stub: return blank frames for testing without hardware
            rgb   = np.zeros((480, 640, 3), dtype=np.uint8)
            depth = np.zeros((480, 640),    dtype=np.uint16)
            return rgb, depth

        try:
            # [FILL_AFTER_SDK_INSTALL — exact API from SDK docs]
            # Typical pattern:
            #   frame = self.camera.get_frame()
            #   rgb   = frame.rgb    # H×W×3 uint8 BGR
            #   depth = frame.depth  # H×W uint16 in mm
            #   return rgb, depth
            return None, None   # placeholder
        except Exception as e:
            self.get_logger().warn(f'Camera capture error: {e}')
            return None, None

    def capture(self) -> tuple:
        """
        Direct capture call used by vision_node.py (not via ROS2 topic).
        Returns (rgb_bgr_uint8, depth_uint16_mm) — latest cached frame pair.
        Thread-safe.
        """
        with self._lock:
            if self._latest_rgb is None:
                return self._capture_raw()   # first call — capture fresh
            return self._latest_rgb.copy(), self._latest_depth.copy()

    def destroy_node(self):
        if not self._stub_mode and self.camera is not None:
            # [FILL_AFTER_SDK_INSTALL — close camera stream]
            # self.camera.stop_stream()
            # self.camera.close()
            pass
        super().destroy_node()

def main(args=None):
    rclpy.init(args=args)
    node = HP60CCameraNode()
    try:
        rclpy.spin(node)
    except KeyboardInterrupt:
        pass
    finally:
        node.destroy_node()
        rclpy.shutdown()

if __name__ == '__main__':
    main()
```

**SDK installation on Pi (once SSH works):**
```bash
# 1. Download HP60C SDK from YDLIDAR website or ask hardware team for the package
# 2. Build Python bindings:
cd hp60c_sdk/python
pip install .
# 3. Verify:
python -c "import hp60c_sdk; print('SDK OK')"
```

**Integration with vision_node.py:**
`vision_node.py` holds a reference to the `HP60CCameraNode` instance and calls `camera.capture()` directly — no topic subscription needed for the vision pipeline. The topic publications are for debugging and any future nodes that need camera data.

---

### P1 — vision_node.py (Orchestrator)

This is the ROS2 node that owns all perception. It does NOT do inference directly — it delegates to the sub-modules and manages which mode is active.

**Subscribes to:**
- `/vision_search_request` (VisionSearchRequest) — from planner_node
- `/robot_state` (RobotState) — to know when to switch to HANDOVER mode

**Publishes to:**
- `/vision_status` (String: `LOADING` | `READY`) — startup status
- `/vision_result` (VisionResult) — tool found or not found
- `/hand_status` (HandStatus) — during HANDOVER state only
- `/log_event` (LogEvent) — search events

**Startup sequence:**

```python
# vision_node.py
import rclpy
from rclpy.node import Node
from rclpy.executors import MultiThreadedExecutor
from acare_msgs.msg import VisionSearchRequest, VisionResult, HandStatus, RobotState, LogEvent
from std_msgs.msg import String
from .yolo_infer import YOLOv11ONNX
from .nbv_search import NBVSearch
from .hand_tracker import HandTracker
import threading

class VisionNode(Node):
    def __init__(self):
        super().__init__('vision_node')
        self.mode = 'IDLE'  # 'IDLE', 'SEARCH', 'HANDOVER'
        self.yolo_ready = False
        self.lock = threading.Lock()

        # Publishers
        self.status_pub = self.create_publisher(String, '/vision_status', 10)
        self.result_pub = self.create_publisher(VisionResult, '/vision_result', 10)
        self.hand_pub = self.create_publisher(HandStatus, '/hand_status', 10)
        self.log_pub = self.create_publisher(LogEvent, '/log_event', 10)

        # Subscribers
        self.create_subscription(VisionSearchRequest, '/vision_search_request',
                                 self.on_search_request, 10)
        self.create_subscription(RobotState, '/robot_state',
                                 self.on_robot_state, 10)

        # Publish LOADING immediately
        self.status_pub.publish(String(data='LOADING'))
        self.get_logger().info('Vision node: loading YOLO model...')

        # Load model in a background thread so ROS2 stays alive
        threading.Thread(target=self._load_models, daemon=True).start()

    def _load_models(self):
        self.yolo = YOLOv11ONNX('/models/yolo_int8.onnx', conf_thresh=0.70)
        self.nbv = NBVSearch(self.yolo)
        self.hand_tracker = HandTracker()
        self.yolo_ready = True
        self.status_pub.publish(String(data='READY'))
        self.get_logger().info('Vision node: READY')

    def on_robot_state(self, msg: RobotState):
        with self.lock:
            if msg.state == 'HANDOVER':
                self.mode = 'HANDOVER'
                self.hand_tracker.start()
            elif self.mode == 'HANDOVER':
                self.mode = 'IDLE'
                self.hand_tracker.stop()

    def on_search_request(self, msg: VisionSearchRequest):
        if not self.yolo_ready:
            # Planner should have checked /vision_status — but guard here too
            self.get_logger().warn('Search request arrived before YOLO ready')
            return
        with self.lock:
            self.mode = 'SEARCH'
        # Run in executor thread — this blocks while arm moves + captures
        result = self.nbv.search(
            tool_name=msg.tool,
            publish_hand_cb=None  # hand_tracker not active during search
        )
        self.result_pub.publish(result)
        with self.lock:
            self.mode = 'IDLE'

    # HandTracker runs its own thread, publishing /hand_status directly
```

**Critical rule:** YOLOv11 inference and MediaPipe Hands NEVER run simultaneously. `self.mode` enforces this — when `SEARCH`, `HandTracker` is stopped. When `HANDOVER`, YOLO is not called.

---

### P2 — YOLOv11 ONNX INT8 Inference

> ⚠️ **SPEC CORRECTION:** The spec says TFLite INT8. Use **ONNX INT8** with `onnxruntime` instead. Better tooling, easier debugging, identical accuracy. Benchmarked at ~77 ms/frame on Pi 5 at 640×640 with INT8; use 320×320 for ~40 ms.

**Step 1 — Export (run on your training machine, not Pi):**

```python
# run on laptop/desktop where you trained
from ultralytics import YOLO

model = YOLO('runs/detect/train/weights/best.pt')  # your trained model
model.export(
    format='onnx',
    int8=True,          # INT8 post-training quantisation
    imgsz=320,          # 320×320 for Pi 5 speed — sufficient for table-top
    simplify=True,      # remove unused ONNX ops
    opset=12,           # max compatibility with onnxruntime on Pi
    dynamic=False,      # fixed input shape for edge deployment
)
# Output: best.onnx  — copy this to Pi at /models/yolo_int8.onnx
```

**Step 2 — Inference class (`yolo_infer.py`):**

```python
# acare_vision/yolo_infer.py
import onnxruntime as ort
import numpy as np
import cv2

CLASS_NAMES = [
    'scalpel', 'scissors', 'forceps', 'bandage',
    'gauze', 'thermometer', 'oximeter', 'plaster'
]

class YOLOv11ONNX:
    """
    Wraps an ONNX INT8 YOLOv11 model for inference on Pi 5 CPU.
    """
    def __init__(self, model_path: str, conf_thresh: float = 0.70):
        opts = ort.SessionOptions()
        opts.intra_op_num_threads = 4   # use all Pi 5 cores
        opts.inter_op_num_threads = 1
        opts.graph_optimization_level = ort.GraphOptimizationLevel.ORT_ENABLE_ALL
        self.session = ort.InferenceSession(
            model_path,
            sess_options=opts,
            providers=['CPUExecutionProvider']
        )
        self.input_name = self.session.get_inputs()[0].name
        # Shape: [1, 3, H, W]
        _, _, self.H, self.W = self.session.get_inputs()[0].shape
        self.conf_thresh = conf_thresh

    def preprocess(self, bgr_frame: np.ndarray) -> np.ndarray:
        img = cv2.resize(bgr_frame, (self.W, self.H))
        img = cv2.cvtColor(img, cv2.COLOR_BGR2RGB)
        img = img.astype(np.float32) / 255.0          # normalise [0,1]
        img = np.transpose(img, (2, 0, 1))             # HWC → CHW
        img = np.expand_dims(img, axis=0)              # add batch dim
        return img

    def postprocess(self, output: np.ndarray, orig_h: int, orig_w: int):
        """
        YOLOv11 ONNX output shape: [1, 4+num_classes, num_anchors]
        For 320×320 input: [1, 12, 2100] (8 classes + 4 box coords)
        """
        preds = output[0]                              # [4+C, N]
        preds = preds.T                                # [N, 4+C]

        boxes_xywh = preds[:, :4]                     # cx, cy, w, h (normalised)
        scores = preds[:, 4:]                          # [N, num_classes]

        class_ids = np.argmax(scores, axis=1)
        confidences = scores[np.arange(len(scores)), class_ids]

        # Filter by confidence
        mask = confidences >= self.conf_thresh
        boxes_xywh = boxes_xywh[mask]
        class_ids = class_ids[mask]
        confidences = confidences[mask]

        if len(boxes_xywh) == 0:
            return []

        # Convert cx,cy,w,h (normalised) → x1,y1,x2,y2 (pixel)
        scale_x, scale_y = orig_w / self.W, orig_h / self.H
        cx = boxes_xywh[:, 0] * self.W * scale_x
        cy = boxes_xywh[:, 1] * self.H * scale_y
        bw = boxes_xywh[:, 2] * self.W * scale_x
        bh = boxes_xywh[:, 3] * self.H * scale_y
        x1 = (cx - bw / 2).astype(int)
        y1 = (cy - bh / 2).astype(int)
        x2 = (cx + bw / 2).astype(int)
        y2 = (cy + bh / 2).astype(int)

        # NMS
        boxes_xyxy = np.stack([x1, y1, x2, y2], axis=1).tolist()
        indices = cv2.dnn.NMSBoxes(
            boxes_xyxy, confidences.tolist(),
            score_threshold=self.conf_thresh,
            nms_threshold=0.45
        )
        if len(indices) == 0:
            return []

        results = []
        for i in indices.flatten():
            results.append({
                'class_id': int(class_ids[i]),
                'class_name': CLASS_NAMES[int(class_ids[i])],
                'confidence': float(confidences[i]),
                'bbox': (int(x1[i]), int(y1[i]), int(x2[i]), int(y2[i]))
            })
        return results

    def infer(self, bgr_frame: np.ndarray) -> list:
        h, w = bgr_frame.shape[:2]
        inp = self.preprocess(bgr_frame)
        outputs = self.session.run(None, {self.input_name: inp})
        return self.postprocess(outputs[0], h, w)

    def infer_multi_frame(self, frames: list) -> list:
        """
        Infer on 3 frames (wrist offsets), merge with NMS, return merged detections.
        frames: list of BGR numpy arrays (all same shape)
        """
        all_boxes, all_scores, all_class_ids = [], [], []
        for frame in frames:
            h, w = frame.shape[:2]
            dets = self.infer(frame)
            for d in dets:
                x1, y1, x2, y2 = d['bbox']
                all_boxes.append([x1, y1, x2, y2])
                all_scores.append(d['confidence'])
                all_class_ids.append(d['class_id'])

        if not all_boxes:
            return []

        # Cross-frame NMS
        indices = cv2.dnn.NMSBoxes(
            all_boxes, all_scores,
            score_threshold=self.conf_thresh,
            nms_threshold=0.45
        )
        merged = []
        for i in indices.flatten():
            merged.append({
                'class_id': all_class_ids[i],
                'class_name': CLASS_NAMES[all_class_ids[i]],
                'confidence': all_scores[i],
                'bbox': tuple(all_boxes[i])
            })
        return merged
```

**Performance on Pi 5:**
- 320×320 INT8: ~40–50 ms/frame → sufficient (NBV moves arm ~1 s between frames anyway)
- 640×640 INT8: ~77–150 ms/frame → acceptable but slower
- Use 320×320 as default. If 320×320 accuracy is insufficient for small tools like oximeter, bump to 416×416.

**Temporal consistency check** (inside nbv_search.py, not here):  
If the same class is detected at approximately the same (x, y) pixel location across 2+ consecutive viewpoints, accept it even at confidence ≥ 0.65. This handles partially occluded tools.

---

### P3 — NBV Search (nbv_search.py)

The NBV (Next-Best-View) search is the algorithm that decides which arm pose to move to next when searching for a tool, prioritised by learned probability.

**Data structures:**

```python
# probability_map: dict[zone_name → dict[tool_class → float]]
# All values clamped to [0.05, 0.90]. Sum per zone normalised to 1.0.
probability_map = {
    'zone_A': {'scalpel': 0.4, 'scissors': 0.2, 'forceps': 0.15, ...},
    'zone_B': {'scissors': 0.5, 'forceps': 0.3, ...},
    ...
}

# viewpoints: list of dicts — arm poses corresponding to each zone
# joint_angles filled after hardware assembly and calibration
viewpoints = [
    {'zone': 'zone_A', 'joint_angles': [0.0, 0.5, -0.8, 0.0, 0.3, 0.0]},  # [FILL_AFTER_ASSEMBLY]
    {'zone': 'zone_B', 'joint_angles': [0.4, 0.5, -0.8, 0.0, 0.3, 0.0]},  # [FILL_AFTER_ASSEMBLY]
    {'zone': 'zone_C', 'joint_angles': [-0.4, 0.5, -0.8, 0.0, 0.3, 0.0]}, # [FILL_AFTER_ASSEMBLY]
]
```

**Full NBV search implementation:**

```python
# acare_vision/nbv_search.py
import yaml, time, numpy as np
from pathlib import Path
from .fake_detector import FakeDetector
from .localiser import Localiser
from acare_msgs.msg import VisionResult, ArmCommand, MotionFeedback
import rclpy

PROB_MAP_PATH = Path('/acare_ws/src/acare_bringup/config/probability_map.yaml')
WORKSPACE = {'xmin': -0.4, 'xmax': 0.4, 'ymin': -0.3, 'ymax': 0.3, 'zmin': 0.0, 'zmax': 0.5}

class NBVSearch:
    def __init__(self, yolo_model, node):
        self.yolo = yolo_model
        self.node = node   # parent vision_node for publishing arm commands
        self.fake_detector = FakeDetector()
        self.localiser = Localiser()
        self.probability_map = self._load_map()
        self.viewpoints = self._load_viewpoints()
        # Track last viewpoint's detections for temporal consistency
        self.prev_detections = {}  # class_name → approx pixel centre

    def _load_map(self) -> dict:
        ALL_TOOLS = ['scalpel','scissors','forceps','bandage','gauze','thermometer','oximeter','plaster']
        zones = ['zone_A', 'zone_B', 'zone_C']
        if PROB_MAP_PATH.exists():
            with open(PROB_MAP_PATH) as f:
                loaded = yaml.safe_load(f) or {}
            # Fill in any tools missing from a partial admin-written yaml
            # so normalisation always covers all 8 tools per zone
            for zone in zones:
                if zone not in loaded:
                    loaded[zone] = {}
                for tool in ALL_TOOLS:
                    if tool not in loaded[zone]:
                        loaded[zone][tool] = 0.05   # minimum prior for unlisted tools
            return loaded
        # Cold start: uniform distribution
        return {z: {t: 1.0/len(ALL_TOOLS) for t in ALL_TOOLS} for z in zones}

    def _load_viewpoints(self) -> list:
        # Loaded from system.yaml after calibration. Hardcoded here as placeholder.
        # [FILL_AFTER_ASSEMBLY via python admin.py calibrate]
        return []

    def _sort_zones(self, tool_name: str) -> list:
        """Sort zones by P(tool|zone), highest first."""
        scored = []
        for vp in self.viewpoints:
            zone = vp['zone']
            prob = self.probability_map.get(zone, {}).get(tool_name, 0.05)
            scored.append((prob, vp))
        scored.sort(key=lambda x: x[0], reverse=True)
        return [vp for _, vp in scored]

    def _move_arm_to(self, joint_angles: list) -> bool:
        """Send MOVE command and wait for MotionFeedback.success."""
        cmd = ArmCommand()
        cmd.command = 'MOVE'
        cmd.joint_angles = joint_angles
        cmd.velocity_scale = 0.8
        cmd.blocking = True
        self.node.arm_cmd_pub.publish(cmd)
        # Wait for feedback (blocking via threading.Event set by motion_feedback callback)
        success = self.node.wait_for_motion_feedback(timeout=10.0)
        return success

    def _capture_frames(self, camera) -> tuple:
        """
        Capture 3 RGB+depth frame pairs at small wrist offsets (~2-3 cm).
        Returns list of (rgb_frame, depth_frame).
        CRITICAL: arm must be fully stationary before capture.
        """
        frames = []
        wrist_offsets = [0.0, 0.02, -0.02]   # ±2 cm wrist pitch offset in radians (approx)
        for offset in wrist_offsets:
            # Apply tiny wrist offset via incremental joint 4 adjustment
            # (exact mapping depends on arm kinematics — [FILL_AFTER_ASSEMBLY])
            rgb, depth = camera.capture()      # HP60C SDK call
            frames.append((rgb, depth))
            time.sleep(0.05)                   # 50 ms settle between micro-captures
        return frames

    def _check_temporal_consistency(self, dets: list) -> list:
        """Promote detections to 0.65 threshold if seen at same location in prev viewpoint."""
        promoted = []
        for d in dets:
            cx = (d['bbox'][0] + d['bbox'][2]) // 2
            cy = (d['bbox'][1] + d['bbox'][3]) // 2
            prev = self.prev_detections.get(d['class_name'])
            if prev is not None:
                dist = ((cx - prev[0])**2 + (cy - prev[1])**2) ** 0.5
                if dist < 50 and d['confidence'] >= 0.65:   # within 50px → same object
                    promoted.append(d)
                    continue
            if d['confidence'] >= 0.70:
                promoted.append(d)
        return promoted

    def _update_map(self, zone: str, tool_name: str, found: bool, all_dets: list):
        """Bayesian update with clamping."""
        if zone not in self.probability_map:
            self.probability_map[zone] = {}

        # Primary update for requested tool
        current = self.probability_map[zone].get(tool_name, 0.125)
        self.probability_map[zone][tool_name] = current * (1.5 if found else 0.7)

        # Passive update for all detected tools at this viewpoint
        for det in all_dets:
            t = det['class_name']
            if t != tool_name:
                v = self.probability_map[zone].get(t, 0.125)
                self.probability_map[zone][t] = v * 1.3

        # Normalise
        total = sum(self.probability_map[zone].values())
        if total > 0:
            for t in self.probability_map[zone]:
                self.probability_map[zone][t] /= total

        # Clamp to [0.05, 0.90]
        for t in self.probability_map[zone]:
            self.probability_map[zone][t] = min(max(self.probability_map[zone][t], 0.05), 0.90)

    def save_map(self):
        """Atomic write. Called on clean shutdown."""
        tmp = Path(str(PROB_MAP_PATH) + '.tmp')
        with open(tmp, 'w') as f:
            yaml.dump(self.probability_map, f)
        tmp.rename(PROB_MAP_PATH)   # atomic rename

    def search(self, tool_name: str, camera) -> VisionResult:
        sorted_viewpoints = self._sort_zones(tool_name)
        result = VisionResult()
        result.found = False
        result.tool = tool_name

        for vp in sorted_viewpoints:
            zone = vp['zone']

            # Move arm to viewpoint — wait until stationary
            ok = self._move_arm_to(vp['joint_angles'])
            if not ok:
                continue   # arm error — skip viewpoint

            # Capture 3 frames
            frame_pairs = self._capture_frames(camera)

            # Run YOLO on all 3 frames, merge
            rgb_frames = [p[0] for p in frame_pairs]
            depth_frames = [p[1] for p in frame_pairs]
            all_dets = self.yolo.infer_multi_frame(rgb_frames)

            # Temporal consistency check
            all_dets = self._check_temporal_consistency(all_dets)

            # Update prev detections for next viewpoint
            self.prev_detections = {}
            for d in all_dets:
                cx = (d['bbox'][0] + d['bbox'][2]) // 2
                cy = (d['bbox'][1] + d['bbox'][3]) // 2
                self.prev_detections[d['class_name']] = (cx, cy)

            # Filter to requested tool only
            tool_dets = [d for d in all_dets if d['class_name'] == tool_name]

            # Fake check + workspace filter
            valid = []
            ref_depth = depth_frames[1]  # middle frame depth
            ref_rgb = rgb_frames[1]
            for d in tool_dets:
                from .fake_detector import FakeDetector
                if FakeDetector().is_fake(ref_rgb, ref_depth, d['bbox']):
                    self.node.get_logger().warn(f'Fake object rejected: {d["class_name"]}')
                    continue
                pos = self.localiser.pixel_to_robot(d['bbox'], ref_depth)
                if pos is None:
                    continue  # depth unavailable
                if not self._in_workspace(pos):
                    continue
                d['position_3d'] = pos
                valid.append(d)

            # Bayesian map update
            self._update_map(zone, tool_name, found=len(valid) > 0, all_dets=all_dets)

            if valid:
                # Pick best: highest confidence, tiebreak = closest to neutral arm position
                valid.sort(key=lambda d: d['confidence'], reverse=True)
                best = valid[0]
                result.found = True
                result.x, result.y, result.z = best['position_3d']
                result.confidence = best['confidence']
                result.zone = zone
                return result

        return result   # found=False

    def _in_workspace(self, pos: tuple) -> bool:
        x, y, z = pos
        w = WORKSPACE
        return w['xmin'] <= x <= w['xmax'] and w['ymin'] <= y <= w['ymax'] and w['zmin'] <= z <= w['zmax']
```

---

### P4 — Fake Object Detection (fake_detector.py)

Dual-signal approach: Laplacian texture variance + depth variance. **Both** must be below threshold to reject as fake. This prevents false rejection of shiny real surgical tools (which have low texture but high depth variance).

```python
# acare_vision/fake_detector.py
import cv2
import numpy as np
import yaml
from pathlib import Path

THRESHOLDS_PATH = Path('/acare_ws/src/acare_bringup/config/thresholds.yaml')

class FakeDetector:
    def __init__(self):
        with open(THRESHOLDS_PATH) as f:
            cfg = yaml.safe_load(f)
        fd = cfg.get('fake_detection', {})
        self.texture_thresh = fd.get('texture_variance_threshold', 120.0)
        self.depth_thresh   = fd.get('depth_variance_threshold', 0.002)

    def is_fake(self, rgb_frame: np.ndarray, depth_frame: np.ndarray, bbox: tuple) -> bool:
        """
        Returns True if object is likely a fake/printed replica.
        rgb_frame : H×W×3 uint8
        depth_frame: H×W float32 or uint16 (metres or mm — see note)
        bbox       : (x1, y1, x2, y2) pixel coords
        """
        x1, y1, x2, y2 = bbox
        # Guard against empty ROI
        if x2 <= x1 or y2 <= y1:
            return False

        # --- Signal 1: Texture variance via Laplacian ---
        roi_gray = cv2.cvtColor(rgb_frame[y1:y2, x1:x2], cv2.COLOR_RGB2GRAY)
        texture_var = cv2.Laplacian(roi_gray, cv2.CV_64F).var()

        # --- Signal 2: Depth variance ---
        depth_roi = depth_frame[y1:y2, x1:x2].astype(np.float32)
        # HP60C depth is in mm — convert to metres for consistent threshold
        depth_roi_m = depth_roi / 1000.0
        valid_depth = depth_roi_m[depth_roi_m > 0]

        if len(valid_depth) < 10:
            # Depth unavailable — fall back to texture only, mark as uncertain
            # Do NOT reject on texture alone (too many false positives on shiny tools)
            return False   # give benefit of the doubt; log DEPTH_UNAVAILABLE separately

        depth_var = np.var(valid_depth)

        # Both signals below threshold → fake
        is_fake = (texture_var < self.texture_thresh) and (depth_var < self.depth_thresh)
        return is_fake
```

**Calibration procedure** (run `python admin.py calibrate`, Step 6):
1. Place 20 real surgical tools one at a time → record texture_var and depth_var for each.
2. Place 20 3D-printed replicas → record same.
3. Find threshold that separates the two distributions cleanly.
4. Write to `thresholds.yaml`. The defaults (120.0, 0.002) are starting estimates — **must be calibrated on real hardware**.

---

### P5 — 3D Localisation (localiser.py)

Converts a bounding box centre pixel + depth value into (x, y, z) in robot base frame. No Open3D. No point cloud. Direct depth pixel read.

```python
# acare_vision/localiser.py
import numpy as np
import yaml
from pathlib import Path

SYSTEM_YAML = Path('/acare_ws/src/acare_bringup/config/system.yaml')

class Localiser:
    def __init__(self):
        with open(SYSTEM_YAML) as f:
            cfg = yaml.safe_load(f)
        cam = cfg['camera']
        # Intrinsics — set during calibration
        self.fx = cam['fx']           # focal length x (pixels)   [FILL_AFTER_ASSEMBLY]
        self.fy = cam['fy']           # focal length y (pixels)   [FILL_AFTER_ASSEMBLY]
        self.cx = cam['cx']           # principal point x         [FILL_AFTER_ASSEMBLY]
        self.cy = cam['cy']           # principal point y         [FILL_AFTER_ASSEMBLY]
        # Extrinsics: 4×4 transform from camera frame to robot base frame
        # Stored as flat list [r00,r01,...r33] in system.yaml
        T_flat = cam['T_robot_camera']    # [FILL_AFTER_ASSEMBLY]
        self.T = np.array(T_flat).reshape(4, 4)

    def pixel_to_robot(self, bbox: tuple, depth_frame: np.ndarray) -> tuple | None:
        """
        bbox       : (x1, y1, x2, y2)
        depth_frame: H×W uint16 or float32, values in mm (HP60C native)
        Returns (x, y, z) in robot base frame in metres, or None if depth invalid.
        """
        x1, y1, x2, y2 = bbox
        u = (x1 + x2) // 2   # bbox centre pixel x
        v = (y1 + y2) // 2   # bbox centre pixel y

        # Clamp to frame bounds
        h, w = depth_frame.shape[:2]
        u = min(max(u, 0), w - 1)
        v = min(max(v, 0), h - 1)

        depth_mm = float(depth_frame[v, u])
        if depth_mm <= 0 or depth_mm > 4000:   # HP60C range: 0.2–4.0 m = 200–4000 mm
            return None

        depth_m = depth_mm / 1000.0

        # Pixel (u, v) + depth → 3D in camera frame
        X_cam = (u - self.cx) * depth_m / self.fx
        Y_cam = (v - self.cy) * depth_m / self.fy
        Z_cam = depth_m

        # Transform to robot base frame
        P_cam = np.array([X_cam, Y_cam, Z_cam, 1.0])
        P_robot = self.T @ P_cam

        return (float(P_robot[0]), float(P_robot[1]), float(P_robot[2]))

    def compute_pregrasp(self, grasp_point: tuple, approach_dist_m: float = 0.05) -> tuple:
        """Return a point 5 cm above the grasp point (in robot Z)."""
        x, y, z = grasp_point
        return (x, y, z + approach_dist_m)
```

**Camera intrinsics calibration:** Use OpenCV `calibrateCamera()` with a checkerboard pattern (9×6 squares) before deployment. Run via `admin.py calibrate` Step 2. Store `fx, fy, cx, cy` in `system.yaml`.

**Extrinsics calibration:** Mount calibration target at known robot-frame coordinates, capture from camera, compute T_robot_camera using `cv2.solvePnP`. Store as flat 16-element list in `system.yaml`.

---

### P6 — Hand Tracking (hand_tracker.py)

Runs **only during HANDOVER state**. Detects open palm, computes 3D palm position for dynamic arm approach. MediaPipe Hands.

```python
# acare_vision/hand_tracker.py
import mediapipe as mp
import numpy as np
import threading
import time
from acare_msgs.msg import HandStatus

mp_hands = mp.solutions.hands

# Landmark indices
WRIST         = 0
INDEX_MCP     = 5;  INDEX_TIP  = 8
MIDDLE_MCP    = 9;  MIDDLE_TIP = 12
RING_MCP      = 13; RING_TIP   = 16
PINKY_MCP     = 17; PINKY_TIP  = 20
THUMB_TIP     = 4;  THUMB_IP   = 3

class HandTracker:
    def __init__(self, localiser, camera, hand_pub, log_pub):
        self.localiser = localiser
        self.camera    = camera
        self.hand_pub  = hand_pub
        self.log_pub   = log_pub
        self.running   = False
        self._thread   = None
        self.hands = mp_hands.Hands(
            static_image_mode=False,
            max_num_hands=1,
            min_detection_confidence=0.70,
            min_tracking_confidence=0.60
        )

    def start(self):
        self.running = True
        self._thread = threading.Thread(target=self._loop, daemon=True)
        self._thread.start()

    def stop(self):
        self.running = False
        if self._thread:
            self._thread.join(timeout=2.0)

    def _loop(self):
        while self.running:
            rgb, depth = self.camera.capture()
            msg = self._process(rgb, depth)
            self.hand_pub.publish(msg)
            time.sleep(0.05)   # ~20 FPS

    def _process(self, rgb_frame: np.ndarray, depth_frame: np.ndarray) -> HandStatus:
        msg = HandStatus()
        msg.hand_detected = False
        msg.is_open       = False
        msg.palm_up       = False
        msg.confidence    = 0.0

        results = self.hands.process(rgb_frame)
        if not results.multi_hand_landmarks:
            return msg

        h, w = rgb_frame.shape[:2]
        lm = results.multi_hand_landmarks[0].landmark

        msg.hand_detected = True
        msg.confidence = 0.8   # MediaPipe doesn't expose per-frame confidence directly

        # --- is_open: 3+ fingers extended ---
        fingers_extended = 0
        for tip_idx, pip_idx in [
            (INDEX_TIP, 6), (MIDDLE_TIP, 10), (RING_TIP, 14), (PINKY_TIP, 18)
        ]:
            # Tip y < PIP y means finger is extended (y increases downward in image)
            if lm[tip_idx].y < lm[pip_idx].y:
                fingers_extended += 1
        # Thumb: compare tip x vs IP x (lateral direction)
        if abs(lm[THUMB_TIP].x - lm[THUMB_IP].x) > 0.04:
            fingers_extended += 1
        msg.is_open = fingers_extended >= 3

        # --- palm_up: mean fingertip y < wrist y ---
        fingertip_y_mean = np.mean([lm[INDEX_TIP].y, lm[MIDDLE_TIP].y,
                                     lm[RING_TIP].y,  lm[PINKY_TIP].y])
        msg.palm_up = fingertip_y_mean < lm[WRIST].y

        # --- 3D palm centre ---
        palm_lm_indices = [WRIST, INDEX_MCP, MIDDLE_MCP, RING_MCP, PINKY_MCP]
        px = int(np.mean([lm[i].x for i in palm_lm_indices]) * w)
        py = int(np.mean([lm[i].y for i in palm_lm_indices]) * h)
        pos = self.localiser.pixel_to_robot((px-5, py-5, px+5, py+5), depth_frame)
        if pos:
            msg.x, msg.y, msg.z = pos

        return msg
```

---

### P7 — Bayesian Probability Map

This is not a separate file — it lives inside `nbv_search.py` (the `_update_map` and `save_map` methods above). Key rules:

**Update multipliers:**
- Tool found in zone: `× 1.5`
- Tool NOT found in zone: `× 0.7`
- Passive update (other tools seen): `× 1.3`

**Normalisation:** After every update, sum all tool probabilities in the zone and divide each by the sum.

**Clamping:** `P = min(max(P, 0.05), 0.90)` — after normalise. Prevents any zone/tool from reaching 0 (always searched) or 1 (monopolises all searches).

**Persistence:**
- Clean shutdown → atomic write to `probability_map.yaml` (`.tmp` → rename).
- Boot with `.tmp` present → incomplete write → delete `.tmp`, load `.yaml`.
- Boot with neither file → uniform distribution (cold start).

**Admin prior:** Before a demo, admin runs `python admin.py calibrate` Step 5 to define viewpoints and sets `probability_map.yaml` manually to reflect expected tool placement. This makes the first demo run fast.

---

## 3. Software Pipeline

---

### S1 — normaliser.py

Called in the voice pipeline after Deepgram STT, before Groq intent parsing. Cleans and normalises raw transcripts.

```python
# acare_voice/normaliser.py
import re

FILLER_WORDS = {
    'um', 'uh', 'er', 'ah', 'hmm', 'please', 'kindly',
    'can you', 'could you', 'would you', 'can you please',
    'could you please', 'would you please'
}

# Simple unambiguous aliases ONLY — contextual ones go to Groq
SIMPLE_ALIASES = {
    'bandage cloth': 'bandage',
    'gauze pad':     'gauze',
    'gauze swab':    'gauze',
    'pulse ox':      'oximeter',
    'spo2':          'oximeter',
    'temp probe':    'thermometer',
    'band aid':      'plaster',
    'band-aid':      'plaster',
    'adhesive strip':'plaster',
}

TOOL_NAMES = {
    'scalpel','scissors','forceps','bandage',
    'gauze','thermometer','oximeter','plaster'
}

def normalise(raw: str) -> dict:
    """
    Returns:
        {
            'text': str,           # cleaned text
            'multi_tool': bool,    # True if 2+ tools detected
            'tools_found': list    # list of tool names if multi_tool
        }
    """
    text = raw.lower().strip()

    # Step 1: Strip punctuation (keep spaces)
    text = re.sub(r"[^\w\s']", '', text)

    # Step 2: Strip filler words/phrases (longest first to avoid partial matches)
    for filler in sorted(FILLER_WORDS, key=len, reverse=True):
        text = text.replace(filler, ' ')
    text = ' '.join(text.split())   # collapse multiple spaces

    # Step 3: Simple alias expansion
    for alias, canonical in SIMPLE_ALIASES.items():
        text = text.replace(alias, canonical)

    # Step 4: Multi-tool detection
    found_tools = [t for t in TOOL_NAMES if re.search(r'\b' + t + r'\b', text)]
    multi_tool = len(found_tools) >= 2

    return {
        'text': text,
        'multi_tool': multi_tool,
        'tools_found': found_tools
    }
```

---

### S2 — auth_node.py

> ⚠️ **SPEC CORRECTION:** Spec says "d-vector embeddings". Use **SpeechBrain ECAPA-TDNN** (`speechbrain/spkrec-ecapa-voxceleb`). This is the current recommended model. EER ~0.8% vs x-vector's 3.2%. Significantly more robust to noisy OT environments.

> ⚠️ **SPEC CORRECTION:** Spec says "MobileNet-based face embedding" — vague. Use **InsightFace `buffalo_sc`**: combines MobileNet RetinaFace detection + MobileFaceNet ArcFace recognition. ~24 ms CPU. 512-D embeddings.

**Models used:**
1. **Speaker verification:** `speechbrain/spkrec-ecapa-voxceleb` (ECAPA-TDNN, ~17 MB)
2. **Face verification:** InsightFace `buffalo_sc` (~40 MB bundle)
3. **Passive face detection (always-on):** MediaPipe FaceDetection (lightweight, ~3 MB)

```python
# acare_auth/verify_voice.py
from speechbrain.inference.speaker import EncoderClassifier
import torch, numpy as np

class VoiceVerifier:
    """ECAPA-TDNN speaker verification."""
    THRESHOLD = 0.85   # cosine similarity — from system.yaml

    def __init__(self):
        self.classifier = EncoderClassifier.from_hparams(
            source='speechbrain/spkrec-ecapa-voxceleb',
            savedir='/models/ecapa_tdnn',
            run_opts={'device': 'cpu'}
        )

    def embed(self, audio_tensor: torch.Tensor) -> np.ndarray:
        """audio_tensor: 1D torch float32 at 16 kHz"""
        with torch.no_grad():
            emb = self.classifier.encode_batch(audio_tensor.unsqueeze(0))
        return emb.squeeze().numpy()  # shape: (192,)

    def verify(self, audio_tensor: torch.Tensor, stored_embedding: np.ndarray) -> tuple:
        emb = self.embed(audio_tensor)
        # Cosine similarity
        sim = float(np.dot(emb, stored_embedding) /
                    (np.linalg.norm(emb) * np.linalg.norm(stored_embedding) + 1e-8))
        return sim >= self.THRESHOLD, sim
```

```python
# acare_auth/verify_face.py
import insightface
import numpy as np

class FaceVerifier:
    """InsightFace buffalo_sc: RetinaFace detection + MobileFaceNet ArcFace."""
    THRESHOLD = 0.78    # cosine similarity — from system.yaml

    def __init__(self):
        self.app = insightface.app.FaceAnalysis(
            name='buffalo_sc',
            providers=['CPUExecutionProvider']
        )
        self.app.prepare(ctx_id=-1, det_size=(320, 320))

    def embed(self, bgr_frame: np.ndarray) -> np.ndarray | None:
        """Returns 512-D ArcFace embedding, or None if no face detected."""
        faces = self.app.get(bgr_frame)
        if not faces:
            return None
        # Take the largest face (most likely the authenticated user)
        largest = max(faces, key=lambda f: (f.bbox[2]-f.bbox[0]) * (f.bbox[3]-f.bbox[1]))
        return largest.normed_embedding  # 512-D, already L2 normalised

    def verify(self, bgr_frame: np.ndarray, stored_embedding: np.ndarray) -> tuple:
        emb = self.embed(bgr_frame)
        if emb is None:
            return False, 0.0
        sim = float(np.dot(emb, stored_embedding))   # both L2 normalised → dot = cosine sim
        return sim >= self.THRESHOLD, sim
```

```python
# acare_auth/face_detect.py
# Passive always-on detection — NOT recognition. Just detects presence.
import mediapipe as mp

class PassiveFaceDetector:
    """Lightweight face presence detector — triggers login flow."""
    def __init__(self):
        self.detector = mp.solutions.face_detection.FaceDetection(
            model_selection=0,           # 0 = short-range model (< 2m) — suits OT workspace
            min_detection_confidence=0.6
        )

    def face_present(self, rgb_frame) -> bool:
        results = self.detector.process(rgb_frame)
        return results.detections is not None and len(results.detections) > 0
```

**users.db schema:**

```python
# acare_auth/enrol.py — SQLite schema
import sqlite3, numpy as np, io
from cryptography.fernet import Fernet

CREATE_TABLE = """
CREATE TABLE IF NOT EXISTS users (
    id            TEXT PRIMARY KEY,
    name          TEXT NOT NULL,
    role          TEXT NOT NULL,
    voice_emb     BLOB NOT NULL,    -- ECAPA-TDNN 192-D float32 as bytes
    face_emb      BLOB NOT NULL,    -- ArcFace 512-D float32 as bytes
    registered_at TEXT NOT NULL,
    active        INTEGER DEFAULT 1,
    handover_z_offset REAL DEFAULT 0.0   -- per-user height preference in metres
)
"""

def emb_to_blob(arr: np.ndarray) -> bytes:
    buf = io.BytesIO()
    np.save(buf, arr)
    return buf.getvalue()

def blob_to_emb(blob: bytes) -> np.ndarray:
    return np.load(io.BytesIO(blob))
```

**Login state machine (scripted — not free conversation):**

```
IDLE
  └─ face detected by PassiveFaceDetector
       └─ FACE_DETECTED
            └─ lookup face embedding in users.db → match found?
                 ├─ YES → TTS "Welcome {name}. Say confirm to log in."
                 │         → GREETING_SENT
                 │              └─ voice sample captured simultaneously with "confirm"
                 │                   └─ ECAPA embed → cosine sim ≥ 0.85?
                 │                        ├─ YES → session created → LOGGED_IN
                 │                        └─ NO  → TTS "Identity not recognised." → IDLE
                 └─ NO  → TTS "Please identify yourself." → MANUAL_FALLBACK
```

---

### S3 — dialogue_node.py (LangGraph)

Two operating modes controlled by `/robot_state`:

| Mode | Active When | Behaviour |
|---|---|---|
| ASSISTANT MODE | `state == LOGGED_OUT` | Groq conversational agent — ACARE intro + auth guidance only |
| DIALOGUE MODE | `state == STANDBY / LISTENING / PROCESSING` | LangGraph intent clarity + clarification + context + interruption |

**LangGraph graph structure:**

```python
# acare_dialogue/dialogue_node.py
from langgraph.graph import StateGraph, END
from typing import TypedDict, Optional

class DialogueState(TypedDict):
    raw_text:       str
    intent:         Optional[dict]     # {tool, action, confidence} from Groq
    tool_resolved:  Optional[str]
    confidence:     float
    clarification:  Optional[str]
    pronoun_found:  bool
    multi_tool:     bool
    interrupted:    bool
    session_memory: dict

def intent_clarity_check(state: DialogueState) -> DialogueState:
    """Route based on confidence and pronoun presence."""
    conf = state['intent']['confidence'] if state['intent'] else 0.0
    text = state['raw_text']
    pronouns = ['it', 'that', 'the one', 'the smaller', 'the bigger', 'that one']
    state['pronoun_found'] = any(p in text for p in pronouns)
    if conf >= 0.80 and not state['pronoun_found']:
        state['tool_resolved'] = state['intent']['tool']
    return state

def route_after_clarity(state: DialogueState) -> str:
    if state.get('multi_tool'):
        return 'clarification'
    if state.get('pronoun_found'):
        return 'context_resolver'
    if state['intent'] and state['intent']['confidence'] >= 0.80:
        return 'auth_gate'
    return 'clarification'

def clarification_node(state: DialogueState) -> DialogueState:
    """Generate clarification question via Groq."""
    from groq import Groq
    client = Groq()
    prompt = f"The user said: '{state['raw_text']}'. Generate a short clarification question (max 10 words) to resolve the ambiguous tool request."
    resp = client.chat.completions.create(
        model='llama3-8b-8192',
        messages=[{'role': 'user', 'content': prompt}],
        temperature=0.3,
        max_tokens=30
    )
    state['clarification'] = resp.choices[0].message.content.strip()
    return state

def context_resolver(state: DialogueState) -> DialogueState:
    """Resolve pronouns using session memory."""
    mem = state['session_memory']
    text = state['raw_text']
    if 'it' in text or 'that' in text:
        if mem.get('current_task') and mem['current_task'].get('tool'):
            state['tool_resolved'] = mem['current_task']['tool']
        elif mem.get('tools_fetched'):
            state['tool_resolved'] = mem['tools_fetched'][-1]['tool']
    return state

def interruption_handler(state: DialogueState) -> DialogueState:
    """New command arrived while task active — set interrupted flag."""
    state['interrupted'] = True
    return state

def build_graph() -> StateGraph:
    g = StateGraph(DialogueState)
    g.add_node('intent_clarity', intent_clarity_check)
    g.add_node('clarification',  clarification_node)
    g.add_node('context_resolver', context_resolver)
    g.add_node('interruption',   interruption_handler)
    g.add_node('auth_gate',      lambda s: s)   # pass-through; planner takes over

    g.set_entry_point('intent_clarity')
    g.add_conditional_edges('intent_clarity', route_after_clarity, {
        'clarification':    'clarification',
        'context_resolver': 'context_resolver',
        'auth_gate':        'auth_gate',
    })
    g.add_edge('clarification',    END)   # TTS clarification, wait for reply
    g.add_edge('context_resolver', 'auth_gate')
    g.add_edge('auth_gate',        END)
    return g.compile()
```

**Session memory** (reset on logout):

```python
session_memory = {
    'tools_fetched': [],           # [{'tool': str, 'timestamp': float, 'zone': str}]
    'conversation_history': [],    # capped at 20 turns
    'current_task': {},            # {'tool': str, 'status': str}
    'pending_clarification': False,
    'last_command': ''
}
```

History cap: if `len(history) > 20`, summarise oldest 10 turns via Groq into one summary turn.

---

### S4 — planner_node.py

The master orchestrator. Owns the full pick-and-place sequence. Does NOT do motor control — sends commands via embedded_interface_node.

**Internal task states (not published externally):**

```
IDLE → VISION_SEARCH → PRE_GRASP → GRASPING → HOLDING →
MOVING_TO_HANDOVER → HANDOVER → COMPLETE
```

**get_world_state():**

```python
def get_world_state(self) -> dict:
    return {
        'robot_state':      self.current_robot_state,
        'safety_severity':  self.latest_safety_severity,   # '' | 'WARNING' | 'CRITICAL' | 'ESTOP'
        'vision_ready':     self.vision_ready,
        'network_ok':       self.network_ok,
        'arm_holding':      self.latest_gripper_force > 0.5,  # N
        'gripper_force':    self.latest_gripper_force,
    }
```

**Full task execution (simplified skeleton):**

```python
async def execute_task(self, intent: ValidatedIntent):
    pipeline_start = time.monotonic()

    # 0. World state check
    ws = self.get_world_state()
    if not ws['network_ok']:
        await self.tts('Voice service unavailable.', urgent=True)
        return

    # 1. Vision ready check
    if not ws['vision_ready']:
        await self.tts('System initialising. Please wait.')
        await self.wait_for_vision_ready(timeout=30.0)

    # 2. Open gripper
    self.publish_gripper_cmd('RELEASE')
    await self.wait_for_gripper_force_zero(timeout=3.0)

    # 3. NBV search
    vision_start = time.monotonic()
    search_req = VisionSearchRequest(tool=intent.tool)
    self.vision_search_pub.publish(search_req)
    vision_result = await self.wait_for_vision_result(timeout=30.0)
    vision_ms = int((time.monotonic() - vision_start) * 1000)

    if not vision_result.found:
        await self.tts(f'Cannot locate {intent.tool}. Can you confirm it is on the tray?')
        # ... retry flow (see spec Section XI)
        return

    # 4. IK solve
    grasp_pt = (vision_result.x, vision_result.y, vision_result.z)
    pregrasp_pt = self.localiser.compute_pregrasp(grasp_pt)
    joint_angles = self.ik_solver.solve(pregrasp_pt)
    if joint_angles is None:
        await self.tts(f'Unable to reach the {intent.tool}. Please reposition it.')
        return

    # 5. Motion: pre-grasp → grasp
    motion_start = time.monotonic()
    await self.tts(f'Fetching {intent.tool} for {intent.name}. One moment.')

    ok = await self.send_arm_cmd('MOVE', joint_angles, blocking=True)
    if not ok: return

    grasp_angles = self.ik_solver.solve(grasp_pt)
    ok = await self.send_arm_cmd('MOVE', grasp_angles, blocking=True)
    if not ok: return

    ok = await self.send_gripper_cmd('GRASP', force_target=3.0, blocking=True)
    if not ok or self.latest_gripper_force < 0.5:
        # Grasp failed
        await self.tts(f'Grasp failed. Please reposition the {intent.tool}.')
        await self.send_arm_cmd('MOVE_NEUTRAL', blocking=True)
        return

    # 6. Move to handover zone
    handover_angles = self.ik_solver.solve(self.handover_zone_pos)
    await self.send_arm_cmd('MOVE', handover_angles, blocking=True)
    motion_ms = int((time.monotonic() - motion_start) * 1000)

    # 7. Three-check handover
    await self.tts(f'{intent.tool} ready. Please face the camera.')
    handover_ok = await self.handover_protocol.run(intent, timeout=30.0)

    if not handover_ok:
        # Timeout — safe deposit
        await self.tts(f'No collection detected. Returning {intent.tool} to tray.')
        await self.send_arm_cmd('MOVE', self.safe_drop_angles, blocking=True)
        await self.send_gripper_cmd('RELEASE')
        return

    # 8. Complete
    total_ms = int((time.monotonic() - pipeline_start) * 1000)
    await self.tts('Handover complete. Is there anything else?')
    await self.send_arm_cmd('MOVE_NEUTRAL', blocking=True)
    self.log(intent, vision_ms, motion_ms, total_ms, vision_result.zone)
    self.nbv_search.save_map()
```

---

### S5 — ik_solver.py

> ⚠️ Cannot be built until hardware team provides DH parameters and joint limits. All DH values below are `[FILL_AFTER_ASSEMBLY]`.

**Method:** Damped Least Squares (DLS). Handles near-singular configurations without diverging.

```python
# acare_planner/ik_solver.py
import numpy as np
import yaml
from pathlib import Path

class IKSolver:
    """
    6-DOF DLS IK solver.
    DH parameters and joint limits loaded from system.yaml after assembly.
    """
    DAMPING      = 0.05
    MAX_ITER     = 100
    POS_TOL      = 0.001  # 1 mm
    ORI_TOL      = 0.01   # rad

    def __init__(self, system_yaml_path: str):
        with open(system_yaml_path) as f:
            cfg = yaml.safe_load(f)
        arm = cfg['arm']
        # DH: list of {a, alpha, d, theta_offset} per joint [FILL_AFTER_ASSEMBLY]
        self.dh = arm['dh_params']
        # Joint limits [FILL_AFTER_ASSEMBLY]
        self.q_min = np.array(arm['joint_limits_min'])
        self.q_max = np.array(arm['joint_limits_max'])
        # Home position
        self.q_home = np.array(arm['neutral_joint_angles'])

    def _dh_transform(self, a, alpha, d, theta) -> np.ndarray:
        """Compute 4×4 DH transform matrix for one joint."""
        ct, st = np.cos(theta), np.sin(theta)
        ca, sa = np.cos(alpha), np.sin(alpha)
        return np.array([
            [ct,  -st*ca,  st*sa,  a*ct],
            [st,   ct*ca, -ct*sa,  a*st],
            [0,    sa,     ca,     d   ],
            [0,    0,      0,      1   ]
        ])

    def forward_kinematics(self, q: np.ndarray) -> np.ndarray:
        """Compute 4×4 end-effector transform from joint angles q[6]."""
        T = np.eye(4)
        for i, p in enumerate(self.dh):
            T = T @ self._dh_transform(p['a'], p['alpha'], p['d'], q[i] + p['theta_offset'])
        return T

    def _numerical_jacobian(self, q: np.ndarray, eps: float = 1e-4) -> np.ndarray:
        """6×6 Jacobian via finite differences. Rows: [dx,dy,dz,drx,dry,drz]."""
        T0 = self.forward_kinematics(q)
        p0 = T0[:3, 3]
        J = np.zeros((6, 6))
        for i in range(6):
            q2 = q.copy(); q2[i] += eps
            T2 = self.forward_kinematics(q2)
            # Position rows
            J[:3, i] = (T2[:3, 3] - p0) / eps
            # Orientation rows (axis-angle approximation)
            R_delta = T2[:3, :3] @ T0[:3, :3].T
            J[3, i] = R_delta[2, 1] / eps
            J[4, i] = R_delta[0, 2] / eps
            J[5, i] = R_delta[1, 0] / eps
        return J

    def solve(self, target_pos: tuple, target_ori: np.ndarray = None,
              q_init: np.ndarray = None) -> np.ndarray | None:
        """
        Solve IK for target_pos (x,y,z) in robot base frame.
        target_ori: optional 3×3 rotation matrix. If None, only position is controlled.
        Returns joint_angles[6] or None if no solution found.
        """
        q = q_init if q_init is not None else self.q_home.copy()
        target_p = np.array(target_pos)

        for _ in range(self.MAX_ITER):
            T = self.forward_kinematics(q)
            e_pos = target_p - T[:3, 3]

            if target_ori is not None:
                R_err = target_ori @ T[:3, :3].T
                e_ori = np.array([R_err[2,1], R_err[0,2], R_err[1,0]])
                e = np.concatenate([e_pos, e_ori])
            else:
                e = e_pos
                # Use only position rows of Jacobian
            
            if np.linalg.norm(e_pos) < self.POS_TOL:
                if target_ori is None or np.linalg.norm(e[3:]) < self.ORI_TOL:
                    return q

            J = self._numerical_jacobian(q)
            if target_ori is None:
                J = J[:3, :]

            # DLS update: Δq = J^T (J J^T + λ²I)^{-1} e
            lam2 = self.DAMPING ** 2
            A = J @ J.T + lam2 * np.eye(J.shape[0])
            dq = J.T @ np.linalg.solve(A, e)
            q = q + dq

            # Clamp to joint limits
            q = np.clip(q, self.q_min, self.q_max)

        return None   # did not converge

    def solve_with_fallback(self, target_pos: tuple) -> np.ndarray | None:
        """Try solve, then try 90° rotated approach, then fail."""
        sol = self.solve(target_pos)
        if sol is not None:
            return sol
        # Try rotated approach orientation (90° around Z)
        R90 = np.array([[0,-1,0],[1,0,0],[0,0,1]], dtype=float)
        sol = self.solve(target_pos, target_ori=R90)
        return sol  # None if still failed
```

---

### S6 — handover.py

The three-check sequential handover verification protocol.

```python
# acare_planner/handover.py
import asyncio, time
from acare_msgs.msg import HandStatus, AuthResult

class HandoverProtocol:
    FACE_CHECK_INTERVAL = 0.5   # seconds
    FACE_SIM_THRESHOLD  = 0.78
    FACE_FAIL_MAX       = 3
    TOTAL_TIMEOUT       = 30.0  # seconds

    def __init__(self, auth_node_ref, voice_node_ref, gripper_pub, tts_fn):
        self.auth   = auth_node_ref
        self.voice  = voice_node_ref
        self.tts    = tts_fn
        self.gripper_pub = gripper_pub
        self.latest_hand: HandStatus = HandStatus()
        self.voice_confirm_received = False

    async def run(self, intent, hand_status_sub, timeout: float = 30.0) -> bool:
        deadline = time.monotonic() + timeout

        # --- CHECK 1: Continuous face verification ---
        face_fails = 0
        while time.monotonic() < deadline:
            sim = self.auth.get_current_face_similarity()   # runs every 0.5s in auth_node
            if sim >= self.FACE_SIM_THRESHOLD:
                face_fails = 0
                break
            face_fails += 1
            if face_fails >= self.FACE_FAIL_MAX:
                await self.tts('Please face the camera.')
                face_fails = 0
            await asyncio.sleep(self.FACE_CHECK_INTERVAL)
        else:
            return False   # timeout

        # --- CHECK 2: Hand detection ---
        await self.tts('Please place your open palm under the gripper.')
        while time.monotonic() < deadline:
            hs = self.latest_hand
            if hs.hand_detected:
                if not hs.is_open:
                    await self.tts('Please open your palm.')
                elif not hs.palm_up:
                    await self.tts('Please turn your palm upward.')
                else:
                    break   # hand OK
            await asyncio.sleep(0.1)
        else:
            return False

        # --- CHECK 3: Voice confirmation ---
        await self.tts('Say take to receive.')
        self.voice_confirm_received = False
        while time.monotonic() < deadline:
            if self.voice_confirm_received:
                break
            await asyncio.sleep(0.05)
        else:
            return False

        # All three checks passed → release
        from acare_msgs.msg import GripperCommand
        cmd = GripperCommand(); cmd.command = 'RELEASE'
        self.gripper_pub.publish(cmd)
        await asyncio.sleep(1.0)   # wait for force to drop

        # Height preference update
        # (stored back to users.db via auth_node if user said 'lower'/'higher')
        return True

    def on_voice_confirm(self, word: str):
        if word.strip().lower() in ('take', 'yes', 'got it'):
            self.voice_confirm_received = True

    def on_hand_status(self, msg: HandStatus):
        self.latest_hand = msg
```

---

### S7 — state_manager.py

```python
# acare_planner/state_manager.py
import rclpy, threading, time
from rclpy.node import Node
from acare_msgs.msg import RobotState, StateTransition, SafetyAlert
from std_msgs.msg import String

VALID_TRANSITIONS = {
    'OFFLINE':    {'LOGGED_OUT'},
    'LOGGED_OUT': {'STANDBY'},
    'STANDBY':    {'LISTENING', 'LOGGED_OUT'},
    'LISTENING':  {'PROCESSING', 'STANDBY'},
    'PROCESSING': {'EXECUTING', 'STANDBY'},
    'EXECUTING':  {'HOLDING', 'ESTOP'},
    'HOLDING':    {'HANDOVER', 'ESTOP'},
    'HANDOVER':   {'STANDBY', 'ESTOP'},
    'ESTOP':      {'STANDBY'},
    'ERROR':      {'OFFLINE'},
}

LOGOUT_ALLOWED_FROM = {'STANDBY', 'ESTOP', 'LOGGED_OUT'}
NO_LOGOUT_FROM      = {'EXECUTING', 'HOLDING', 'HANDOVER'}

class StateManager(Node):
    def __init__(self):
        super().__init__('state_manager')
        self.state = 'OFFLINE'
        self.active_user_id = ''
        self._lock = threading.Lock()
        self._inactivity_timer = None

        self.state_pub = self.create_publisher(RobotState, '/robot_state', 10)
        self.create_subscription(StateTransition, '/state_transition', self.on_transition, 10)
        self.create_subscription(SafetyAlert, '/safety_alert', self.on_safety_alert, 10)

        self._transition('LOGGED_OUT')   # boot

    def on_transition(self, msg: StateTransition):
        with self._lock:
            target = msg.target_state
            # Logout guard
            if target == 'LOGGED_OUT' and self.state in NO_LOGOUT_FROM:
                self.get_logger().warn(f'Logout rejected from {self.state}')
                return
            self._transition(target)

    def _transition(self, target: str):
        allowed = VALID_TRANSITIONS.get(self.state, set())
        if target not in allowed and target != self.state:
            self.get_logger().error(f'Invalid transition {self.state} → {target}')
            return
        self.state = target
        msg = RobotState()
        msg.state = target
        msg.active_user_id = self.active_user_id
        self.state_pub.publish(msg)
        self.get_logger().info(f'State → {target}')
        self._reset_inactivity_timer()

    def _reset_inactivity_timer(self):
        if self._inactivity_timer:
            self._inactivity_timer.cancel()
        if self.state == 'STANDBY':
            self._inactivity_timer = threading.Timer(300.0, self._auto_logout)
            self._inactivity_timer.start()

    def _auto_logout(self):
        with self._lock:
            self.get_logger().info('Session timeout — auto-logout')
            # TTS via topic
            self._transition('LOGGED_OUT')

    def on_safety_alert(self, msg: SafetyAlert):
        if msg.severity == 'ESTOP':
            with self._lock:
                self._transition('ESTOP')
```

---

### S8 — safety_node.py

```python
# acare_safety/safety_node.py
import rclpy, yaml
from rclpy.node import Node
from sensor_msgs.msg import LaserScan
from acare_msgs.msg import MotionFeedback, SafetyAlert
from pathlib import Path

THRESHOLDS_PATH = Path('/acare_ws/src/acare_bringup/config/thresholds.yaml')

class SafetyNode(Node):
    def __init__(self):
        super().__init__('safety_node')
        with open(THRESHOLDS_PATH) as f:
            cfg = yaml.safe_load(f)['safety']
        self.T = cfg   # shorthand

        self.alert_pub = self.create_publisher(SafetyAlert, '/safety_alert', 10)
        self.create_subscription(LaserScan, '/scan', self.on_lidar, 10)
        self.create_subscription(MotionFeedback, '/motion_feedback', self.on_telemetry, 10)

    def _publish_alert(self, severity: str, reason: str, source: str):
        msg = SafetyAlert()
        msg.severity = severity
        msg.reason   = reason
        msg.source   = source
        self.alert_pub.publish(msg)
        self.get_logger().warn(f'[{severity}] {source}: {reason}')

    def on_lidar(self, msg: LaserScan):
        """Check proximity in ±60° arc (front of robot)."""
        import math
        n = len(msg.ranges)
        # Front arc: roughly middle third of scan
        front = msg.ranges[n//3 : 2*n//3]
        valid = [r for r in front if msg.range_min < r < msg.range_max]
        if not valid:
            return
        min_dist_mm = min(valid) * 1000   # metres → mm

        if min_dist_mm < self.T['lidar_stop_mm']:
            self._publish_alert('ESTOP', f'Person {min_dist_mm:.0f}mm from robot', 'lidar')
        elif min_dist_mm < self.T['lidar_caution_mm']:
            self._publish_alert('WARNING', f'Person {min_dist_mm:.0f}mm — reduced speed', 'lidar')

    def on_telemetry(self, msg: MotionFeedback):
        """Check MCU sensor values from 50 Hz telemetry."""
        # Joint currents
        for i, curr in enumerate(msg.joint_currents):
            if curr > self.T['current_limit_A']:
                self._publish_alert('ESTOP', f'Joint {i+1} overcurrent {curr:.1f}A', 'current')
            elif curr > self.T['current_warning_A']:
                self._publish_alert('WARNING', f'Joint {i+1} current {curr:.1f}A', 'current')

        # Temperatures
        for i, temp in enumerate(msg.temperatures):
            if temp > self.T['temperature_estop_C']:
                self._publish_alert('ESTOP', f'Joint {i+1} overtemp {temp:.1f}°C', 'temp')
            elif temp > self.T['temperature_slow_C']:
                self._publish_alert('CRITICAL', f'Joint {i+1} temp {temp:.1f}°C', 'temp')
            elif temp > self.T['temperature_warning_C']:
                self._publish_alert('WARNING', f'Joint {i+1} temp {temp:.1f}°C', 'temp')

        # Gripper force
        if msg.gripper_force > self.T['gripper_force_limit_N']:
            self._publish_alert('ESTOP', f'Gripper force spike {msg.gripper_force:.1f}N', 'gripper')
        elif msg.gripper_force > self.T['gripper_force_warning_N']:
            self._publish_alert('WARNING', f'Gripper force {msg.gripper_force:.1f}N', 'gripper')
```

---

### S9 — embedded_interface_node (C++)

This is a C++ ROS2 node with a `MutuallyExclusiveCallbackGroup` for the heartbeat so it never competes with command processing.

```cpp
// acare_embedded_interface/interface_node.cpp
#include <rclcpp/rclcpp.hpp>
#include <serial/serial.h>   // ROS serial library
#include <acare_msgs/msg/arm_command.hpp>
#include <acare_msgs/msg/gripper_command.hpp>
#include <acare_msgs/msg/motion_feedback.hpp>
#include <acare_msgs/msg/emergency_signal.hpp>
#include <std_msgs/msg/string.hpp>
#include <nlohmann/json.hpp>
#include <chrono>

using json = nlohmann::json;
using namespace std::chrono_literals;

class EmbeddedInterfaceNode : public rclcpp::Node {
public:
    EmbeddedInterfaceNode() : Node("embedded_interface_node") {
        // MutuallyExclusive callback group for heartbeat
        hb_group_ = create_callback_group(
            rclcpp::CallbackGroupType::MutuallyExclusive);
        cmd_group_ = create_callback_group(
            rclcpp::CallbackGroupType::MutuallyExclusive);

        // Open UART
        serial_.setPort("/dev/ttyS0");
        serial_.setBaudrate(1000000);  // 1 Mbps
        serial_.open();

        // Publishers
        feedback_pub_ = create_publisher<acare_msgs::msg::MotionFeedback>(
            "/motion_feedback", rclcpp::QoS(10).best_effort());

        // Subscribers
        auto cmd_opts = rclcpp::SubscriptionOptions();
        cmd_opts.callback_group = cmd_group_;
        arm_sub_ = create_subscription<acare_msgs::msg::ArmCommand>(
            "/arm_command", rclcpp::QoS(10).reliable(),
            std::bind(&EmbeddedInterfaceNode::on_arm_command, this, std::placeholders::_1),
            cmd_opts);
        gripper_sub_ = create_subscription<acare_msgs::msg::GripperCommand>(
            "/gripper_command", rclcpp::QoS(10).reliable(),
            std::bind(&EmbeddedInterfaceNode::on_gripper_command, this, std::placeholders::_1),
            cmd_opts);
        estop_sub_ = create_subscription<acare_msgs::msg::EmergencySignal>(
            "/emergency_stop", rclcpp::QoS(10).reliable(),
            std::bind(&EmbeddedInterfaceNode::on_estop, this, std::placeholders::_1),
            cmd_opts);

        // Heartbeat timer — MutuallyExclusive group
        heartbeat_timer_ = create_wall_timer(
            200ms,
            std::bind(&EmbeddedInterfaceNode::send_heartbeat, this),
            hb_group_);

        // Status reader timer at 50 Hz
        status_timer_ = create_wall_timer(
            20ms,
            std::bind(&EmbeddedInterfaceNode::read_status, this));

        RCLCPP_INFO(get_logger(), "EmbeddedInterface: UART open at 1 Mbps");
    }

private:
    void send_heartbeat() {
        json cmd;
        cmd["command"]     = "HEARTBEAT";
        cmd["timestamp"]   = std::chrono::system_clock::now().time_since_epoch().count();
        cmd["robot_state"] = current_robot_state_;
        send_json(cmd);
    }

    void on_arm_command(const acare_msgs::msg::ArmCommand::SharedPtr msg) {
        json cmd;
        cmd["command"] = msg->command;
        if (!msg->joint_angles.empty())
            cmd["joint_angles"] = msg->joint_angles;
        cmd["velocity_scale"] = msg->velocity_scale;
        cmd["accel_limit"]    = msg->accel_limit;
        send_json(cmd);
    }

    void on_gripper_command(const acare_msgs::msg::GripperCommand::SharedPtr msg) {
        json cmd;
        cmd["command"]      = msg->command;   // "GRASP" or "RELEASE"
        cmd["force_target"] = msg->force_target;
        send_json(cmd);
    }

    void on_estop(const acare_msgs::msg::EmergencySignal::SharedPtr) {
        json cmd; cmd["command"] = "ESTOP";
        send_json(cmd);   // bypasses all queues — sent immediately
    }

    void send_json(const json& j) {
        std::string s = j.dump() + "\n";
        if (serial_.isOpen())
            serial_.write(s);
    }

    void read_status() {
        if (!serial_.available()) return;
        std::string line = serial_.readline();
        try {
            auto j = json::parse(line);
            acare_msgs::msg::MotionFeedback fb;
            // Populate feedback from MCU JSON
            auto ja = j["joint_positions"].get<std::vector<float>>();
            fb.joint_positions.assign(ja.begin(), ja.end());
            auto jv = j["joint_velocities"].get<std::vector<float>>();
            fb.joint_velocities.assign(jv.begin(), jv.end());
            auto jc = j["joint_currents"].get<std::vector<float>>();
            fb.joint_currents.assign(jc.begin(), jc.end());
            auto jt = j["temperatures"].get<std::vector<float>>();
            fb.temperatures.assign(jt.begin(), jt.end());
            fb.gripper_force = j["gripper_force"].get<float>();
            fb.imu_roll      = j["imu"]["roll"].get<float>();
            fb.imu_pitch     = j["imu"]["pitch"].get<float>();
            fb.imu_yaw       = j["imu"]["yaw"].get<float>();
            fb.success       = (j["fault_code"].get<int>() == 0);
            feedback_pub_->publish(fb);
        } catch (...) {
            RCLCPP_WARN(get_logger(), "Failed to parse MCU status line");
        }
    }

    serial::Serial serial_;
    std::string current_robot_state_ = "LOGGED_OUT";
    rclcpp::CallbackGroup::SharedPtr hb_group_, cmd_group_;
    rclcpp::TimerBase::SharedPtr heartbeat_timer_, status_timer_;
    rclcpp::Publisher<acare_msgs::msg::MotionFeedback>::SharedPtr feedback_pub_;
    rclcpp::Subscription<acare_msgs::msg::ArmCommand>::SharedPtr arm_sub_;
    rclcpp::Subscription<acare_msgs::msg::GripperCommand>::SharedPtr gripper_sub_;
    rclcpp::Subscription<acare_msgs::msg::EmergencySignal>::SharedPtr estop_sub_;
};

int main(int argc, char **argv) {
    rclcpp::init(argc, argv);
    auto node = std::make_shared<EmbeddedInterfaceNode>();
    rclcpp::executors::MultiThreadedExecutor exec;
    exec.add_node(node);
    exec.spin();
    rclcpp::shutdown();
}
```

---

### S10 — log_node.py

```python
# acare_logging/log_node.py
import rclpy, sqlite3, uuid, gzip, csv, io, os, time
from rclpy.node import Node
from acare_msgs.msg import LogEvent
from pathlib import Path

DB_PATH      = Path('/acare_ws/logs/acare_logs.db')
MAX_SIZE_MB  = 200
BATCH_SIZE   = 10

CREATE_SQL = """
CREATE TABLE IF NOT EXISTS events (
    event_id        TEXT PRIMARY KEY,
    timestamp       TEXT,
    staff_id        TEXT,
    staff_name      TEXT,
    event_type      TEXT,
    tool            TEXT,
    zone_found      TEXT,
    grasp_attempts  INTEGER,
    success         INTEGER,
    failure_reason  TEXT,
    sensor_values   TEXT,
    safety_severity TEXT,
    voice_e2e_ms    INTEGER,
    vision_search_ms INTEGER,
    motion_ms       INTEGER,
    total_task_ms   INTEGER
)
"""

class LogNode(Node):
    def __init__(self):
        super().__init__('log_node')
        DB_PATH.parent.mkdir(parents=True, exist_ok=True)
        self.conn = sqlite3.connect(str(DB_PATH), check_same_thread=False)
        self.conn.execute(CREATE_SQL)
        self.conn.commit()
        self.buffer = []

        self.create_subscription(LogEvent, '/log_event', self.on_log, 10)
        self.get_logger().info('LogNode ready')

    def on_log(self, msg: LogEvent):
        self.buffer.append((
            str(uuid.uuid4()),
            str(msg.timestamp),
            msg.user_id,
            '',   # name looked up if needed
            msg.event_type,
            msg.tool,
            '',   # zone_found
            0,    # grasp_attempts
            1 if msg.state else 0,
            msg.description,
            '{}',
            msg.safety_severity,
            msg.voice_e2e_ms,
            msg.vision_search_ms if hasattr(msg, 'vision_search_ms') else 0,
            msg.motion_ms if hasattr(msg, 'motion_ms') else 0,
            msg.total_task_ms if hasattr(msg, 'total_task_ms') else 0,
        ))
        if len(self.buffer) >= BATCH_SIZE:
            self._flush()

    def _flush(self):
        self.conn.executemany(
            "INSERT OR IGNORE INTO events VALUES (?,?,?,?,?,?,?,?,?,?,?,?,?,?,?,?)",
            self.buffer
        )
        self.conn.commit()
        self.buffer.clear()
        self._check_rotation()

    def _check_rotation(self):
        size_mb = DB_PATH.stat().st_size / (1024 * 1024)
        if size_mb < MAX_SIZE_MB:
            return
        # Archive oldest 20% rows to gzipped CSV
        rows = self.conn.execute(
            "SELECT * FROM events ORDER BY timestamp ASC LIMIT "
            f"(SELECT COUNT(*) FROM events) * 20 / 100"
        ).fetchall()
        archive_path = DB_PATH.parent / f'archive_{int(time.time())}.csv.gz'
        with gzip.open(archive_path, 'wt') as f:
            writer = csv.writer(f)
            writer.writerows(rows)
        ids = [r[0] for r in rows]
        self.conn.execute(
            f"DELETE FROM events WHERE event_id IN ({','.join('?'*len(ids))})", ids)
        self.conn.commit()
        self.get_logger().info(f'Log rotation: archived {len(rows)} rows → {archive_path.name}')
```

---

### S11 — admin_cli.py

```python
# acare_admin/admin_cli.py
"""
Usage examples:
  python admin.py enrol --name "Dr. Sharma" --role surgeon
  python admin.py revoke --id staff_001
  python admin.py list-staff
  python admin.py set-api-key --service deepgram --key YOUR_KEY
  python admin.py set-api-key --service groq --key YOUR_KEY
  python admin.py set-threshold --sensor joint_current --value 8.0
  python admin.py show-logs --last 50
  python admin.py export-logs --format csv
  python admin.py status
  python admin.py calibrate
  python admin.py demo-mode --enable
  python admin.py demo-mode --disable
"""
import argparse, sqlite3, yaml, json, sys
from pathlib import Path
from cryptography.fernet import Fernet

DB_PATH       = Path('/acare_ws/logs/acare_logs.db')
KEY_PATH      = Path('/etc/acare/key.bin')
API_KEYS_PATH = Path('/etc/acare/api_keys.yaml')
THRESHOLDS    = Path('/acare_ws/src/acare_bringup/config/thresholds.yaml')

def get_fernet() -> Fernet:
    if not KEY_PATH.exists():
        key = Fernet.generate_key()
        KEY_PATH.parent.mkdir(parents=True, exist_ok=True)
        KEY_PATH.write_bytes(key)
    return Fernet(KEY_PATH.read_bytes())

def cmd_enrol(args):
    """Trigger enrolment — calls auth_node enrolment service via ROS2."""
    import subprocess
    subprocess.run([
        'ros2', 'service', 'call', '/enrol_staff',
        'acare_msgs/srv/EnrolStaff',
        f'{{"name": "{args.name}", "role": "{args.role}"}}'
    ])

def cmd_set_api_key(args):
    f = get_fernet()
    keys = {}
    if API_KEYS_PATH.exists():
        keys = yaml.safe_load(API_KEYS_PATH.read_text()) or {}
    keys[args.service] = f.encrypt(args.key.encode()).decode()
    API_KEYS_PATH.parent.mkdir(parents=True, exist_ok=True)
    API_KEYS_PATH.write_text(yaml.dump(keys))
    print(f'API key for {args.service} saved (encrypted).')

def cmd_set_threshold(args):
    with open(THRESHOLDS) as f:
        cfg = yaml.safe_load(f)
    sensor_map = {
        'joint_current': ('safety', 'current_limit_A'),
        'joint_temp':    ('safety', 'temperature_estop_C'),
        'gripper_force': ('safety', 'gripper_force_limit_N'),
    }
    if args.sensor not in sensor_map:
        print(f'Unknown sensor. Valid: {list(sensor_map)}')
        return
    section, key = sensor_map[args.sensor]
    cfg[section][key] = float(args.value)
    with open(THRESHOLDS, 'w') as f:
        yaml.dump(cfg, f)
    print(f'Threshold {args.sensor} set to {args.value}')

def cmd_show_logs(args):
    conn = sqlite3.connect(str(DB_PATH))
    rows = conn.execute(
        f"SELECT timestamp, staff_id, event_type, tool, success FROM events "
        f"ORDER BY timestamp DESC LIMIT {args.last}"
    ).fetchall()
    for r in rows:
        print(r)

def cmd_demo_mode(args):
    """Demo mode: disable biometric checks for exhibition."""
    cfg_path = Path('/acare_ws/src/acare_bringup/config/system.yaml')
    with open(cfg_path) as f:
        cfg = yaml.safe_load(f)
    cfg['demo_mode'] = args.enable
    with open(cfg_path, 'w') as f:
        yaml.dump(cfg, f)
    print(f"Demo mode {'ENABLED' if args.enable else 'DISABLED'}")

def cmd_calibrate(args):
    """7-step calibration procedure."""
    print("=== ACARE Calibration Procedure ===")
    print("Step 1: Joint homing (Teensy will move each joint to limit switch)")
    input("  Press ENTER to start joint homing...")
    import subprocess
    subprocess.run(['ros2', 'service', 'call', '/calibrate',
                    'std_srvs/srv/Trigger', '{}'])
    print("Step 2: Camera calibration — place checkerboard in workspace")
    input("  Press ENTER when checkerboard is in place...")
    # ... (each step triggers the appropriate ROS2 service)
    print("Calibration complete.")

if __name__ == '__main__':
    parser = argparse.ArgumentParser(prog='admin')
    sub = parser.add_subparsers(dest='cmd')

    p_enrol = sub.add_parser('enrol')
    p_enrol.add_argument('--name', required=True)
    p_enrol.add_argument('--role', required=True)

    p_key = sub.add_parser('set-api-key')
    p_key.add_argument('--service', required=True, choices=['deepgram','groq'])
    p_key.add_argument('--key', required=True)

    p_thresh = sub.add_parser('set-threshold')
    p_thresh.add_argument('--sensor', required=True)
    p_thresh.add_argument('--value', required=True)

    p_logs = sub.add_parser('show-logs')
    p_logs.add_argument('--last', type=int, default=20)

    p_demo = sub.add_parser('demo-mode')
    p_demo.add_argument('--enable', action='store_true')
    p_demo.add_argument('--disable', dest='enable', action='store_false')
    p_demo.set_defaults(enable=False)

    sub.add_parser('calibrate')

    args = parser.parse_args()
    dispatch = {
        'enrol':         cmd_enrol,
        'set-api-key':   cmd_set_api_key,
        'set-threshold': cmd_set_threshold,
        'show-logs':     cmd_show_logs,
        'demo-mode':     cmd_demo_mode,
        'calibrate':     cmd_calibrate,
    }
    if args.cmd in dispatch:
        dispatch[args.cmd](args)
    else:
        parser.print_help()
```

---

### S12 — supervisor.py

Standalone Python script — NOT a ROS2 node. Launched separately from the ROS2 stack.

```python
# acare_bringup/supervisor.py
import subprocess, time, sys

# Nodes that will be auto-restarted on crash
AUTO_RESTART = ['log_node', 'admin_node', 'dialogue_node']
# Nodes that will NOT be restarted — trigger ESTOP instead
CRITICAL     = ['safety_node', 'embedded_interface_node', 'state_manager', 'planner_node']

# ROS2 node names as they appear in `ros2 node list`
NODE_ROS_NAMES = {
    'log_node':                '/log_node',
    'admin_node':              '/admin_node',
    'dialogue_node':           '/dialogue_node',
    'safety_node':             '/safety_node',
    'embedded_interface_node': '/embedded_interface_node',
    'state_manager':           '/state_manager',
    'planner_node':            '/planner_node',
}

NODE_CMDS = {
    'log_node':               ['ros2', 'run', 'acare_logging',           'log_node'],
    'admin_node':             ['ros2', 'run', 'acare_admin',             'admin_node'],
    'dialogue_node':          ['ros2', 'run', 'acare_dialogue',          'dialogue_node'],
    'safety_node':            ['ros2', 'run', 'acare_safety',            'safety_node'],
    'embedded_interface_node':['ros2', 'run', 'acare_embedded_interface','interface_node'],
    'state_manager':          ['ros2', 'run', 'acare_planner',           'state_manager'],
    'planner_node':           ['ros2', 'run', 'acare_planner',           'planner_node'],
}

processes = {}

def start_node(name: str):
    cmd = NODE_CMDS[name]
    processes[name] = subprocess.Popen(cmd)
    print(f'[supervisor] Started {name} (PID {processes[name].pid})')

def is_node_alive(ros_name: str) -> bool:
    """
    Check if a ROS2 node is alive using `ros2 node list`.
    This is reliable — it queries the ROS2 graph directly rather than
    checking the launcher process exit code, which can be misleading.
    """
    try:
        result = subprocess.run(
            ['ros2', 'node', 'list'],
            capture_output=True, text=True, timeout=5.0
        )
        return ros_name in result.stdout
    except subprocess.TimeoutExpired:
        return True   # assume alive if we can't check — avoid false ESTOP

def trigger_estop():
    subprocess.run([
        'ros2', 'topic', 'pub', '--once', '/emergency_stop',
        'acare_msgs/msg/EmergencySignal', '{reason: "Critical node crash"}'
    ])

def monitor():
    while True:
        time.sleep(5)
        for name in list(NODE_CMDS.keys()):
            ros_name = NODE_ROS_NAMES[name]
            if not is_node_alive(ros_name):
                print(f'[supervisor] {name} not found in ROS2 graph — crashed')
                if name in AUTO_RESTART:
                    print(f'[supervisor] Restarting {name}...')
                    time.sleep(1)
                    start_node(name)
                elif name in CRITICAL:
                    print(f'[supervisor] CRITICAL node {name} crashed — triggering ESTOP')
                    trigger_estop()

if __name__ == '__main__':
    for name in NODE_CMDS:
        start_node(name)
    monitor()
```

---

## 4. Configuration Files

### system.yaml (corrected — edge-tts, no Google Cloud TTS)

```yaml
robot:
  workspace:
    xmin: -0.4
    xmax:  0.4
    ymin: -0.3
    ymax:  0.3
    zmin:  0.0
    zmax:  0.5
  safe_drop_zone:  {x: 0.0, y: 0.35, z: 0.05}   # [FILL_AFTER_ASSEMBLY]
  handover_zone:   {x: 0.0, y: 0.40, z: 0.10}   # [FILL_AFTER_ASSEMBLY]
  handover_height_adjustment_m: 0.05

arm:
  dh_params:   # [FILL_AFTER_ASSEMBLY — required for IK solver]
    # Gearbox ratios (confirmed): Joint 2 (Shoulder) = 22:1, Joint 3 (Elbow) = 15:1
    # Joints 4,5,6 ratios: [FILL_AFTER_ASSEMBLY — confirm with hardware team]
    - {a: 0.0, alpha: 0.0, d: 0.0, theta_offset: 0.0}  # Joint 1 placeholder
    - {a: 0.0, alpha: 0.0, d: 0.0, theta_offset: 0.0}  # Joint 2 placeholder
    - {a: 0.0, alpha: 0.0, d: 0.0, theta_offset: 0.0}  # Joint 3 placeholder
    - {a: 0.0, alpha: 0.0, d: 0.0, theta_offset: 0.0}  # Joint 4 placeholder
    - {a: 0.0, alpha: 0.0, d: 0.0, theta_offset: 0.0}  # Joint 5 placeholder
    - {a: 0.0, alpha: 0.0, d: 0.0, theta_offset: 0.0}  # Joint 6 placeholder
  joint_limits_min: [0.0, 0.0, 0.0, 0.0, 0.0, 0.0]    # [FILL_AFTER_ASSEMBLY]
  joint_limits_max: [0.0, 0.0, 0.0, 0.0, 0.0, 0.0]    # [FILL_AFTER_ASSEMBLY]
  neutral_joint_angles: [0.0, 0.0, 0.0, 0.0, 0.0, 0.0] # [FILL_AFTER_ASSEMBLY]
  link_lengths:
    base_height: 0.0   # [FILL_AFTER_ASSEMBLY]
    upper_arm:   0.0   # [FILL_AFTER_ASSEMBLY]
    forearm:     0.0   # [FILL_AFTER_ASSEMBLY]
    wrist:       0.0   # [FILL_AFTER_ASSEMBLY]
    gripper:     0.0   # [FILL_AFTER_ASSEMBLY]

camera:
  fx: 0.0    # [FILL_AFTER_CALIBRATION]
  fy: 0.0    # [FILL_AFTER_CALIBRATION]
  cx: 0.0    # [FILL_AFTER_CALIBRATION]
  cy: 0.0    # [FILL_AFTER_CALIBRATION]
  T_robot_camera:  # 4×4 as flat 16-element list [FILL_AFTER_CALIBRATION]
    [1,0,0,0, 0,1,0,0, 0,0,1,0, 0,0,0,1]

vision:
  model_path: '/models/yolo_int8.onnx'
  confidence_threshold: 0.70
  input_size: 320

voice:
  # TTS engines — NOTE: Google Cloud TTS is NOT used. Use edge-tts.
  tts_normal:   edge_tts                 # Microsoft Edge TTS (free, pip install edge-tts)
  tts_safety:   pyttsx3                  # offline, zero latency, for ESTOP/critical
  tts_fallback: kokoro_onnx              # offline fallback if no internet
  edge_tts_voice: 'en-IN-NeerjaNeural'  # or 'en-IN-PrabhatNeural' (male)
  tts_rate: 150                          # words per minute
  use_deepgram: true
  use_groq: true
  network_fail_hold_threshold_seconds: 5
  session_inactivity_timeout_seconds: 300
  handover_timeout_seconds: 30
  estop_keywords: [stop, halt, emergency, abort, ruko, bas]

auth:
  voice_similarity_threshold: 0.85
  face_similarity_threshold:  0.78
  voice_drift_consecutive_threshold: 3
  face_check_interval_s: 0.5
  enrol_voice_samples: 3
  enrol_face_frames:   10

demo_mode: false
```

### thresholds.yaml

```yaml
safety:
  current_limit_A:            8.0
  current_warning_A:          6.0
  temperature_estop_C:       75.0
  temperature_slow_C:        65.0
  temperature_warning_C:     55.0
  velocity_limit_degs:      120.0
  velocity_operational_degs: 80.0
  lidar_caution_mm:          600
  lidar_stop_mm:             400
  gripper_force_limit_N:     15.0
  gripper_force_warning_N:   10.0

fake_detection:
  texture_variance_threshold: 120.0  # MUST calibrate empirically — this is a starting estimate
  depth_variance_threshold:   0.002  # MUST calibrate empirically — this is a starting estimate
```

### probability_map.yaml (example admin-defined prior)

```yaml
# Set this before a demo to reflect expected tool placement.
# All values clamped to [0.05, 0.90] on every Bayesian update.
zone_A:                   # left side of tray
  scalpel:  0.50
  scissors: 0.20
  forceps:  0.15
  bandage:  0.05
  gauze:    0.05
  thermometer: 0.05
zone_B:                   # centre of tray
  scissors: 0.45
  forceps:  0.30
  scalpel:  0.10
  gauze:    0.05
  bandage:  0.05
  thermometer: 0.05
zone_C:                   # right side / sterile tray
  gauze:    0.55
  plaster:  0.30
  bandage:  0.10
  oximeter: 0.05
```

---

## 5. ROS2 Package Structure & acare_msgs

### Directory tree

```
acare_ws/
├── src/
│   ├── acare_msgs/
│   │   ├── msg/
│   │   │   ├── RobotState.msg
│   │   │   ├── StateTransition.msg
│   │   │   ├── Intent.msg
│   │   │   ├── ValidatedIntent.msg
│   │   │   ├── SafetyAlert.msg
│   │   │   ├── HandStatus.msg
│   │   │   ├── AuthResult.msg
│   │   │   ├── VisionResult.msg
│   │   │   ├── VisionSearchRequest.msg
│   │   │   ├── ArmCommand.msg
│   │   │   ├── GripperCommand.msg
│   │   │   ├── MotionFeedback.msg
│   │   │   ├── LogEvent.msg
│   │   │   └── EmergencySignal.msg
│   │   ├── srv/
│   │   │   └── EnrolStaff.srv
│   │   ├── CMakeLists.txt
│   │   └── package.xml
│   ├── acare_voice/
│   │   ├── voice_node.py
│   │   ├── vad.py
│   │   ├── asr.py
│   │   ├── tts.py             # edge-tts + pyttsx3 + kokoro fallback
│   │   ├── keyword_monitor.py
│   │   └── normaliser.py
│   ├── acare_dialogue/
│   │   ├── dialogue_node.py
│   │   ├── assistant_agent.py
│   │   └── nodes/
│   │       ├── clarity_check.py
│   │       ├── clarification.py
│   │       ├── context_resolver.py
│   │       ├── interruption_handler.py
│   │       └── dialogue_manager.py
│   ├── acare_auth/
│   │   ├── auth_node.py
│   │   ├── enrol.py
│   │   ├── verify_voice.py    # ECAPA-TDNN
│   │   ├── verify_face.py     # InsightFace buffalo_sc
│   │   ├── face_detect.py     # MediaPipe FaceDetection (passive)
│   │   └── embeddings/        # users.db (encrypted)
│   ├── acare_vision/
│   │   ├── vision_node.py
│   │   ├── yolo_infer.py      # ONNX INT8 (not TFLite)
│   │   ├── nbv_search.py
│   │   ├── fake_detector.py
│   │   ├── localiser.py
│   │   └── hand_tracker.py
│   ├── acare_planner/
│   │   ├── planner_node.py
│   │   ├── state_machine.py
│   │   ├── state_manager.py
│   │   ├── tool_registry.py
│   │   ├── handover.py
│   │   └── ik_solver.py
│   ├── acare_safety/
│   │   ├── safety_node.py
│   │   ├── lidar_monitor.py
│   │   └── sensor_monitor.py
│   ├── acare_embedded_interface/
│   │   ├── interface_node.cpp
│   │   ├── CMakeLists.txt
│   │   └── package.xml
│   ├── acare_logging/
│   │   └── log_node.py
│   ├── acare_admin/
│   │   └── admin_cli.py
│   └── acare_bringup/
│       ├── launch/
│       │   └── acare.launch.py
│       ├── config/
│       │   ├── system.yaml
│       │   ├── thresholds.yaml
│       │   └── probability_map.yaml
│       └── supervisor.py
├── logs/
│   └── acare_logs.db
└── install/
```

### Key .msg definitions

```
# RobotState.msg
string state
string active_user_id

# StateTransition.msg
string target_state
string reason

# VisionSearchRequest.msg
string tool

# VisionResult.msg
bool found
string tool
float32 x
float32 y
float32 z
float32 confidence
string zone

# HandStatus.msg
bool hand_detected
bool is_open
bool palm_up
float32 x
float32 y
float32 z
float32 confidence

# ArmCommand.msg
string command
float32[] joint_angles
float32 velocity_scale
float32 accel_limit
bool blocking

# GripperCommand.msg
string command
float32 force_target

# MotionFeedback.msg
bool success
string phase
string error
float32[] joint_positions
float32[] joint_velocities
float32[] joint_currents
float32[] temperatures
float32 gripper_force
float32 imu_roll
float32 imu_pitch
float32 imu_yaw

# SafetyAlert.msg
string severity
string reason
string source

# LogEvent.msg
string event_type
string user_id
string tool
string state
string description
int64 timestamp
int64 voice_e2e_ms
int64 vision_search_ms
int64 motion_ms
int64 total_task_ms
string safety_severity

# EmergencySignal.msg
string reason
string source

# EnrolStaff.srv
string name
string role
---
bool success
string staff_id
string message
```

### acare_msgs/CMakeLists.txt (key parts)

```cmake
cmake_minimum_required(VERSION 3.8)
project(acare_msgs)

find_package(ament_cmake REQUIRED)
find_package(rosidl_default_generators REQUIRED)

rosidl_generate_interfaces(${PROJECT_NAME}
  "msg/RobotState.msg"
  "msg/StateTransition.msg"
  "msg/Intent.msg"
  "msg/ValidatedIntent.msg"
  "msg/SafetyAlert.msg"
  "msg/HandStatus.msg"
  "msg/AuthResult.msg"
  "msg/VisionResult.msg"
  "msg/VisionSearchRequest.msg"
  "msg/ArmCommand.msg"
  "msg/GripperCommand.msg"
  "msg/MotionFeedback.msg"
  "msg/LogEvent.msg"
  "msg/EmergencySignal.msg"
  "srv/EnrolStaff.srv"
)

ament_package()
```

---

## 6. Full Dependencies

### requirements.txt (Pi 5 — Python packages)

```
# Inference
onnxruntime>=1.18.0          # ONNX Runtime for YOLOv11 — NOT tflite-runtime

# Vision / Perception
opencv-python-headless>=4.9  # headless (no GUI) for Pi
mediapipe>=0.10.14            # Hands + FaceDetection
insightface>=0.7.3            # buffalo_sc: ArcFace face verification

# Speaker verification
speechbrain>=1.0.0            # ECAPA-TDNN (spkrec-ecapa-voxceleb)
torch>=2.2.0                  # CPU-only — required by SpeechBrain

# VAD
silero-vad                    # Silero VAD v5

# STT
deepgram-sdk>=3.5.0           # Deepgram Nova-2 streaming

# Intent parsing + conversational AI
groq>=0.9.0                   # Groq API (llama3-8b-8192)
langchain-groq>=0.1.0
langgraph>=0.2.0

# TTS — Microsoft Edge TTS (replaces Google Cloud TTS)
edge-tts>=7.2.7               # pip install edge-tts — FREE, no API key
pyttsx3>=2.90                 # ESTOP/safety TTS — offline, zero latency
# Kokoro ONNX for offline TTS fallback (install separately — not on PyPI mainstream)

# Utilities
numpy>=1.26
scipy>=1.12
PyYAML>=6.0
cryptography>=42.0            # Fernet encryption for users.db and API keys
pyserial>=3.5                 # UART to Teensy

# ROS2 Python deps (installed via apt, not pip)
# sudo apt install python3-rclpy python3-std-msgs ros-jazzy-sensor-msgs

# C++ node deps (install via apt)
# sudo apt install ros-jazzy-serial-driver libserial-dev nlohmann-json3-dev

# Admin CLI
argparse                      # stdlib — no install needed

# Export (development machine only — NOT on Pi)
# pip install ultralytics      # only for ONNX export on training machine
```

### API Keys Required

| Service | Free Tier | How to Set |
|---|---|---|
| Deepgram Nova-2 | 12,000 min/year free | `python admin.py set-api-key --service deepgram --key YOUR_KEY` |
| Groq | Generous free tier (rate limited) | `python admin.py set-api-key --service groq --key YOUR_KEY` |
| Microsoft Edge TTS | Completely free, no key | No setup needed — `edge-tts` uses Edge's public endpoint |

### ROS2 Packages (apt)

```bash
sudo apt install ros-jazzy-rclpy ros-jazzy-std-msgs ros-jazzy-sensor-msgs \
     ros-jazzy-geometry-msgs ros-jazzy-launch ros-jazzy-launch-ros
# YDLIDAR T-mini Plus driver:
git clone -b humble https://github.com/YDLIDAR/ydlidar_ros2_driver.git
# HP60C: use YDLIDAR HP60C SDK Python bindings — write custom ROS2 wrapper node
```

---

*End of ACARE Implementation Guide.*  
*Hardware parameters marked `[FILL_AFTER_ASSEMBLY]` must be obtained from the hardware team before `ik_solver.py` and `planner_node.py` can be finalised.*

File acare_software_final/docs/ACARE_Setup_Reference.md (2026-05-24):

# ACARE — Pi Setup & Daily Use Reference

---

## Pi Credentials

| Field | Value |
|---|---|
| Username | `acare` |
| Password | `acare1234` |
| Hostname | `acare` |
| WiFi | `Airtel_Sarsou` |
| IP (typical) | `192.168.1.72` or `192.168.1.73` |

---

## Every Day — Starting Up

### 1. Power on the Pi
Plug in the USB-C power cable. Wait 2 minutes for boot.

### 2. Find the Pi's IP
Run this in PowerShell on your laptop:
```
1..254 | ForEach-Object { ping -n 1 -w 50 192.168.1.$_ > $null }; arp -a
```
Look for a `192.168.1.x` entry that wasn't there before. That's the Pi.

### 3. SSH in
```
ssh acare@192.168.1.72
```
Replace `192.168.1.72` with whatever IP you found. Password: `acare1234`

If you get "WARNING: REMOTE HOST IDENTIFICATION HAS CHANGED", run:
```
ssh-keygen -R 192.168.1.72
```
Then SSH again.

---

## Every Day — Starting the Camera

The camera node must be running before any vision code can use it.

### Start the camera (from acare_ws directory)
```bash
cd ~/acare_ws && ros2 launch ascamera hp60c.launch.py
```

### Verify camera is streaming (in a second SSH session)
```bash
ros2 topic list
```
You should see `/ascamera_hp60c/camera_publisher/rgb0/image` and `/ascamera_hp60c/camera_publisher/depth0/image_raw`.

Check frame rate:
```bash
ros2 topic hz /ascamera_hp60c/camera_publisher/rgb0/image
```
Expected: ~12 Hz.

---

## Every Day — Shutting Down

**Always shut down properly. Never just unplug — it can corrupt the SD card.**

### Stop the camera node
Press `Ctrl+C` in the terminal running the camera launch.

### Shut down the Pi
```bash
sudo shutdown now
```
Wait for the green LED to go dark (~10 seconds), then unplug the power.

---

## Opening a Second SSH Session

Open a new PowerShell window on your laptop and SSH in again with the same command:
```
ssh acare@192.168.1.72
```
You can have as many SSH sessions open simultaneously as you need.

---

## Adding a New WiFi Network

To add your mobile hotspot or a teammate's WiFi so the Pi connects automatically:
```bash
sudo nmcli dev wifi connect "NetworkName" password "NetworkPassword"
```

Or edit the netplan config directly:
```bash
sudo nano /etc/netplan/50-cloud-init.yaml
```
Add the new network under `access-points:`, then apply:
```bash
sudo netplan apply
```

---

## Checking Pi Health

```bash
# Temperature
vcgencmd measure_temp

# Disk usage
df -h

# Memory usage
free -h

# CPU load
top
```

---

## ROS2 Workspace

### Rebuild after code changes
```bash
cd ~/acare_ws && colcon build --symlink-install && source ~/.bashrc
```

### Check all packages are built
```bash
ros2 pkg list | grep acare
```

### Source the workspace manually (if needed)
```bash
source /opt/ros/jazzy/setup.bash
source ~/acare_ws/install/setup.bash
```

---

## Camera SDK Location

The HP60C SDK is extracted at:
```
~/HP60C_ROS/EaiCameraSdk_v1.2.28.20241015/demo/linux_ros/
```

Config files for the camera are at:
```
~/acare_ws/ascamera/configurationfiles/
```
The camera launch must be run from `~/acare_ws/` so it finds this path.

---

## Transferring Files to/from Pi

### Laptop → Pi
```
scp "C:\path\to\file" acare@192.168.1.72:~/
```

### Pi → Laptop
```
scp acare@192.168.1.72:/path/on/pi "C:\destination\on\laptop"
```

---

## If the Pi Won't Connect to WiFi

1. Unplug and replug power, wait 2 minutes
2. Run the network scan command again
3. If still not showing up, the Pi may have gotten a different IP — scan the full range

If it still won't connect after a reboot, the netplan config may be corrupted. Pull the SD card, put it in the card reader, and check `/etc/netplan/50-cloud-init.yaml` on the `writable` partition (requires a Linux machine or WSL to read ext4).

---

## If SSH Says "Connection Refused"

SSH service may not have started. Wait 1 more minute and try again. If it persists after 5 minutes, reboot the Pi.

## If SSH Says "Connection Timed Out"

The Pi is not on the network. Run the IP scan again — it may have a different IP.

---

## Pi Setup History (for reference)

The Pi was set up with:
- Ubuntu Server 24.04.4 LTS (64-bit, aarch64)
- ROS2 Jazzy (ros-jazzy-ros-base)
- All acare_ws packages built (11 acare packages + ascamera)
- Python deps: speechbrain, deepgram-sdk, groq, langgraph, pyttsx3, mediapipe, onnxruntime
- HP60C camera SDK extracted and configured
- unattended-upgrades disabled (prevents background apt from dropping SSH)
- needrestart masked

**Camera confirmed working:** RGB 640×480 BGR8 @ 12.4 Hz, Depth 640×480 16UC1 @ 12.4 Hz, range 489–1330mm validated.

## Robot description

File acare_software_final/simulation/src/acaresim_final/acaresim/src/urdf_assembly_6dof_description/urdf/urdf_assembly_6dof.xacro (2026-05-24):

<?xml version="1.0" ?>
<robot name="urdf_assembly_6dof" xmlns:xacro="http://www.ros.org/wiki/xacro">

<xacro:include filename="$(find urdf_assembly_6dof_description)/urdf/materials.xacro" />
<link name="base_link">
  <inertial>
    <origin xyz="0.00410640824843945 0.00037607678390353186 0.1170490117140184" rpy="0 0 0"/>
    <mass value="0.23793774301536802"/>
    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
  </inertial>
  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
</link>

<link name="eccentric_15_1_3_v1_1">
  <inertial>
    <origin xyz="-4.2789364312553757e-07 1.2124325275913539e-05 0.003439653375908" rpy="0 0 0"/>
    <mass value="0.014600947373706387"/>
    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
  </inertial>
  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
</link>

<link name="shoulder_link_v1_1">
  <inertial>
    <origin xyz="-0.00489670517820693 0.0010482754384108885 0.29147921323786774" rpy="0 0 0"/>
    <mass value="0.22101898904141454"/>
    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
  </inertial>
  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
</link>

<link name="tube_holder_shoulder_elbow_v1_1">
  <inertial>
    <origin xyz="-0.06019707140695683 -0.0013764873428753779 -0.07265959536924965" rpy="0 0 0"/>
    <mass value="0.07199185784738897"/>
    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
  </inertial>
  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
</link>

<link name="eccentric_15_1_4_v1_1">
  <inertial>
    <origin xyz="-4.278936295988144e-07 4.780823860093771e-06 0.001400051031832189" rpy="0 0 0"/>
    <mass value="0.024609049231594064"/>
    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
  </inertial>
  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
</link>

<link name="shoulder_elbow_holder_v1_1">
  <inertial>
    <origin xyz="-0.0010189936781861563 0.0002803066830539462 0.08038184213394745" rpy="0 0 0"/>
    <mass value="0.38096897658202344"/>
    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
  </inertial>
  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
</link>

<link name="eccentric_15_1_2_v1_1">
  <inertial>
    <origin xyz="0.01247457452087002 0.01252054650383455 0.013059300425222409" rpy="0 0 0"/>
    <mass value="0.32157417431877705"/>
    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
  </inertial>
  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
</link>

<link name="tube_holder_shoulder_elbow_v1_2">
  <inertial>
    <origin xyz="0.022110087471271973 -1.6666339447118234e-06 -0.00046608461371533405" rpy="0 0 0"/>
    <mass value="0.07199185784738897"/>
    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
  </inertial>
  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
</link>

<link name="elbow_link_v1_1">
  <inertial>
    <origin xyz="0.004896721242532168 0.000987305481864716 0.29147993619371726" rpy="0 0 0"/>
    <mass value="0.22101898904141454"/>
    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
  </inertial>
  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
</link>

<link name="tube_aluminium_400mm_v1_1">
  <inertial>
    <origin xyz="2.4504038268272077e-07 0.0006963804524399953 0.1993768272375735" rpy="0 0 0"/>
    <mass value="0.07102015612812057"/>
    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
  </inertial>
  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
</link>

<link name="tube_aluminium_400mm_v1_2">
  <inertial>
    <origin xyz="-2.2897606320737562e-07 0.0006962011616549772 0.1993773379931063" rpy="0 0 0"/>
    <mass value="0.07102015612812057"/>
    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
  </inertial>
  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
</link>

<link name="wrist_1_link_v1_1">
  <inertial>
    <origin xyz="-0.018771885723878775 -7.522553827623776e-07 -0.00033245509979451526" rpy="0 0 0"/>
    <mass value="0.06364898919669625"/>
    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
  </inertial>
  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
</link>

<link name="wrist_1_2_link_v1_1">
  <inertial>
    <origin xyz="2.4504039673745037e-07 0.0003191007655391526 0.09149928507437477" rpy="0 0 0"/>
    <mass value="0.03259747953291305"/>
    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
  </inertial>
  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
</link>

<link name="wrist_3_link_v1_1">
  <inertial>
    <origin xyz="-0.016271971624069098 -0.00754054035212065 -0.8405620037838266" rpy="0 0 0"/>
    <mass value="0.10575794368204493"/>
    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
  </inertial>
  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
</link>

<link name="gripper_holder_v1_1">
  <inertial>
    <origin xyz="0.014590589866179327 -8.677483399201907e-05 -0.0006528781386849758" rpy="0 0 0"/>
    <mass value="0.04465962382833497"/>
    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
  </inertial>
  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
</link>

<link name="gripper_top_cover_v1_1">
  <inertial>
    <origin xyz="-1.2682955372696034 -0.061138806424086076 -0.20704437052142066" rpy="0 0 0"/>
    <mass value="0.04450458413708717"/>
    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
  </inertial>
  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
</link>

<link name="MG995_v1_1">
  <inertial>
    <origin xyz="-0.07879853066375689 -0.0044915852854894136 -0.06839214626074952" rpy="0 0 0"/>
    <mass value="0.2556467218698517"/>
    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
  </inertial>
  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
</link>

<link name="gripper_bottom_cover_v1_1">
  <inertial>
    <origin xyz="0.02957864849474268 -1.3434361363736302 0.00037992960479549254" rpy="0 0 0"/>
    <mass value="0.013417914609515144"/>
    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
  </inertial>
  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
</link>



<link name="Spur_Gear__30_teeth__v1_1">
  <inertial>
    <origin xyz="0.039796245040828813 -1.311596511156584 -0.010335567868355655" rpy="0 0 0"/>
    <mass value="0.02625489538583632"/>
    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
  </inertial>
  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
</link>

<link name="gripper_limb_1_v1_2">
  <inertial>
    <origin xyz="1.3305878109250537 0.04843143930124431 0.07777463740099866" rpy="0 0 0"/>
    <mass value="0.009623378174321458"/>
    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
  </inertial>
  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
</link>

<link name="gripper_limb_1_v1_1">
  <inertial>
    <origin xyz="1.288875810925053 0.0806866232501945 -0.01980287496589339" rpy="0 0 0"/>
    <mass value="0.009623378174321458"/>
    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
  </inertial>
  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
</link>

<link name="gripper_limb_2_finger_v1_2">
  <inertial>
    <origin xyz="0.03601810749734448 0.006469330701746632 0.0027340469565539927" rpy="0 0 0"/>
    <mass value="0.008395262805604693"/>
    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
  </inertial>
  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
</link>

<link name="gripper_limb_1_finger_v1_2">
  <inertial>
    <origin xyz="0.03601804778232537 -0.0064693251221964575 -0.002733286629410303" rpy="0 0 0"/>
    <mass value="0.008395211706113329"/>
    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
  </inertial>
  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
</link>

<link name="world"/>

<joint name="world_joint" type="fixed">
  <parent link="world"/>
  <child link="base_link"/>
  <origin xyz="0 0 0" rpy="0 0 0"/>
</joint>

<joint name="base" type="revolute">
  <origin xyz="0.001088 0.000413 0.118349" rpy="0 0 0"/>
  <parent link="base_link"/>
  <child link="eccentric_15_1_3_v1_1"/>
  <axis xyz="0 0 1"/>
  <limit upper="3.14159" lower="-3.14159" effort="100" velocity="100"/>
</joint>

<joint name="Rigid 13" type="fixed">
  <origin xyz="-0.064374 -0.00148 -0.102193" rpy="0 0 0"/>
  <parent link="tube_holder_shoulder_elbow_v1_1"/>
  <child link="shoulder_link_v1_1"/>
</joint>

<joint name="shoulder" type="revolute">
  <origin xyz="0.046587 0.001949 0.236749" rpy="0 0 0"/>
  <parent link="shoulder_elbow_holder_v1_1"/>
  <child link="tube_holder_shoulder_elbow_v1_1"/>
  <axis xyz="-1.0 0.0 0.0"/>
  <limit upper="2.268928" lower="-2.268928" effort="100" velocity="100"/>
</joint>

<joint name="Rigid 22" type="fixed">
  <origin xyz="0.012475 0.012577 0.029206" rpy="0 0 0"/>
  <parent link="eccentric_15_1_2_v1_1"/>
  <child link="eccentric_15_1_4_v1_1"/>
</joint>

<joint name="Rigid 23" type="fixed">
  <origin xyz="0.0 1e-05 0.0028" rpy="0 0 0"/>
  <parent link="eccentric_15_1_4_v1_1"/>
  <child link="shoulder_elbow_holder_v1_1"/>
</joint>

<joint name="Rigid 24" type="fixed">
  <origin xyz="-0.012475 -0.012451 0.006844" rpy="0 0 0"/>
  <parent link="eccentric_15_1_3_v1_1"/>
  <child link="eccentric_15_1_2_v1_1"/>
</joint>

<joint name="elbow" type="revolute">
  <origin xyz="0.025083 0.001556 0.434974" rpy="0 0 0"/>
  <parent link="shoulder_link_v1_1"/>
  <child link="tube_holder_shoulder_elbow_v1_2"/>
  <axis xyz="1.0 -0.0 -0.0"/>
  <limit upper="2.792527" lower="-2.792527" effort="100" velocity="100"/>
</joint>

<joint name="Rigid 26" type="fixed">
  <origin xyz="0.026287 -0.000105 -0.03" rpy="0 0 0"/>
  <parent link="tube_holder_shoulder_elbow_v1_2"/>
  <child link="elbow_link_v1_1"/>
</joint>

<joint name="Rigid 27" type="fixed">
  <origin xyz="-0.064374 -0.00148 -0.102193" rpy="0 0 0"/>
  <parent link="tube_holder_shoulder_elbow_v1_1"/>
  <child link="tube_aluminium_400mm_v1_1"/>
</joint>

<joint name="Rigid 28" type="fixed">
  <origin xyz="0.026287 -0.000105 -0.03" rpy="0 0 0"/>
  <parent link="tube_holder_shoulder_elbow_v1_2"/>
  <child link="tube_aluminium_400mm_v1_2"/>
</joint>

<joint name="wrist_1" type="revolute">
  <origin xyz="-0.025083 0.001481 0.434975" rpy="0 0 0"/>
  <parent link="elbow_link_v1_1"/>
  <child link="wrist_1_link_v1_1"/>
  <axis xyz="-1.0 0.0 0.0"/>
  <limit upper="2.617994" lower="-2.617994" effort="100" velocity="100"/>
</joint>
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

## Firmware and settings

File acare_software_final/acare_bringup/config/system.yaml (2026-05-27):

robot:
  workspace:
    xmin: -0.4
    xmax:  0.4
    ymin: -0.3
    ymax:  0.3
    zmin:  0.0
    zmax:  0.5
  safe_drop_zone:  {x: 0.0, y: 0.35, z: 0.05}   # [FILL_AFTER_ASSEMBLY]
  handover_zone:   {x: 0.0, y: 0.40, z: 0.10}   # [FILL_AFTER_ASSEMBLY]
  handover_height_adjustment_m: 0.05
  kiosk_return_to_rest_seconds: 12

arm:
  # Gearbox ratios confirmed: Joint 2 (Shoulder) = 22:1, Joint 3 (Elbow) = 15:1
  # Joints 4,5,6 ratios: [FILL_AFTER_ASSEMBLY]
  dh_params:
    - {a: 0.0, alpha: 0.0, d: 0.0, theta_offset: 0.0}  # Joint 1 [FILL_AFTER_ASSEMBLY]
    - {a: 0.0, alpha: 0.0, d: 0.0, theta_offset: 0.0}  # Joint 2 [FILL_AFTER_ASSEMBLY]
    - {a: 0.0, alpha: 0.0, d: 0.0, theta_offset: 0.0}  # Joint 3 [FILL_AFTER_ASSEMBLY]
    - {a: 0.0, alpha: 0.0, d: 0.0, theta_offset: 0.0}  # Joint 4 [FILL_AFTER_ASSEMBLY]
    - {a: 0.0, alpha: 0.0, d: 0.0, theta_offset: 0.0}  # Joint 5 [FILL_AFTER_ASSEMBLY]
    - {a: 0.0, alpha: 0.0, d: 0.0, theta_offset: 0.0}  # Joint 6 [FILL_AFTER_ASSEMBLY]
  joint_limits_min: [0.0, 0.0, 0.0, 0.0, 0.0, 0.0]    # [FILL_AFTER_ASSEMBLY]
  joint_limits_max: [0.0, 0.0, 0.0, 0.0, 0.0, 0.0]    # [FILL_AFTER_ASSEMBLY]
  neutral_joint_angles: [0.0, 0.0, 0.0, 0.0, 0.0, 0.0] # [FILL_AFTER_ASSEMBLY]
  # Exhibition / kiosk poses. These are deterministic, pre-approved arm poses.
  kiosk_rest_joint_angles: [0.0, 0.15, -0.35, 0.0, 0.10, 0.0]
  kiosk_interaction_joint_angles: [0.0, -0.10, -0.05, 0.0, -0.05, 0.0]
  link_lengths:
    base_height: 0.0   # [FILL_AFTER_ASSEMBLY]
    upper_arm:   0.0   # [FILL_AFTER_ASSEMBLY]
    forearm:     0.0   # [FILL_AFTER_ASSEMBLY]
    wrist:       0.0   # [FILL_AFTER_ASSEMBLY]
    gripper:     0.0   # [FILL_AFTER_ASSEMBLY]
  control_soft_limits:
    velocity_soft_ratio: 0.90
    current_soft_margin_a: 0.50
    temperature_soft_margin_c: 5.0
    gripper_force_soft_ratio: 0.90
    max_command_velocity_scale: 0.85
    max_command_accel_limit: 0.25
    kiosk_velocity_scale: 0.22
    kiosk_accel_limit: 0.10

camera:
  # Intrinsics — fill after calibration (admin.py calibrate Step 2)
  fx: 554.0   # placeholder — typical 640x480 ~60deg FOV
  fy: 554.0
  cx: 320.0
  cy: 240.0
  # Optional exact ascamera parameter overrides.
  # Leave empty until `vision_node` logs the exact parameter names exported by /ascamera_hp60c.
  control_overrides: {}
  # Extrinsics — 4x4 transform camera→robot base, flat 16-element list
  # Fill after arm assembly and camera mounting (admin.py calibrate Step 5)
  T_robot_camera: [1,0,0,0, 0,1,0,0, 0,0,1,0, 0,0,0,1]

vision:
  model_path: 'models/acare_v26.onnx'
  confidence_threshold: 0.70
  low_light_confidence_threshold: 0.56
  low_light_v_mean_threshold: 75.0
  very_low_light_v_mean_threshold: 52.0
  low_light_enable_tta: true
  low_light_gamma_dark: 1.55
  low_light_gamma_very_dark: 1.85
  low_light_enable_unsharp_mask: true
  input_size: 320
  capture_settle_ms: 120
  # Small wrist micro-offsets around each search viewpoint, in radians.
  # Used to capture 3 frames with slightly different camera angles.
  nbv_wrist_micro_offsets_rad:
    - [0.0, 0.0]
    - [0.035, 0.0]
    - [-0.035, 0.025]
  # Viewpoints defined after arm calibration (admin.py calibrate Step 5)
  # Each entry: {zone: str, joint_angles: [float x6]}
  viewpoints: []

voice:
  tts_normal:   edge_tts
  tts_safety:   pyttsx3
  tts_fallback: kokoro_onnx
  edge_tts_voice: 'en-IN-NeerjaNeural'
  tts_rate: 150
  use_deepgram: true
  use_groq: true
  network_fail_hold_threshold_seconds: 5
  session_inactivity_timeout_seconds: 300
  handover_timeout_seconds: 30
  estop_keywords: [stop, halt, emergency, abort, ruko, bas]

auth:
  voice_similarity_threshold: 0.85
  face_similarity_threshold:  0.78
  voice_drift_consecutive_threshold: 3
  face_check_interval_s: 0.5
  enrol_voice_samples: 3
  enrol_face_frames:   10

demo_mode: true

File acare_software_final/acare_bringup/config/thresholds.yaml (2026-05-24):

safety:
  current_limit_A:            8.0
  current_warning_A:          6.0
  temperature_estop_C:       75.0
  temperature_slow_C:        65.0
  temperature_warning_C:     55.0
  velocity_limit_degs:      120.0
  velocity_operational_degs: 80.0
  lidar_caution_mm:          600
  lidar_stop_mm:             400
  gripper_force_limit_N:     15.0
  gripper_force_warning_N:   10.0

fake_detection:
  # Starting estimates — MUST calibrate empirically (admin.py calibrate Step 6)
  # Place 20 real tools + 20 printed replicas, record values, find threshold
  texture_variance_threshold: 120.0
  depth_variance_threshold:   0.002
